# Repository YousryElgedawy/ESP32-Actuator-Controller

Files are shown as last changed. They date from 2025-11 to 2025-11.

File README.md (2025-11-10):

# ESP32-Actuator-Controller
24V / 20-Channel Actuator Control Board is equipped with an ESP32-S3 and a W5500 Ethernet module for network connectivity, featuring 20 MOSFET-based SSRs to manage actuators along with protection against reverse polarity, overvoltage, short circuits, and ESD.
Board Design Details

- Structure: 4-layer board with a Sig/GND/PWR/Sig stackup, utilizing outer layers for signal traces and inner layers for power distribution.  
- Power Layers: Constructed with 2-ounce copper to handle load currents and withstand high ambient temperatures.  
- Ground Planes:
Layer 2 serves as the main solid GND plane to ensure overall stability. 
Layer 4 features a GND polygon copper pour, functioning as a heat sink and forming a solid ground plane under Layer 3 to create capacitance with the PWR plane. 
A small GND plane is added on Layer 3 over Ethernet and SPI tracks to maintain the same reference plane and minimize impedance mismatch during top-layer routing changes.  
- Power Distribution: Layer 3 incorporates multi-rail polygons for 24V, 5V, and 3.3V supplies.   
Input power polygons are duplicated across layers and connected with stitching vias to support high current demands and minimize temperature rise.  
- High-Speed Signals: Ethernet and SPI signals are routed on the top layer with minimal layer changes, kept as short as possible, and isolated from noise sources including the buck converter, input power connector, and ESP32 antenna, with maximum distance maintained from these sources.   
- RJ45 Connector: Equipped with an internal transformer, Bob-Smith termination, and common-mode choke for optimal signal integrity.   
- SPI Lines: Designed with extremely short traces, maintained at 50-ohm impedance, and implemented with series termination to preserve signal integrity.   
- Power Supply: A cascaded LDO paired with a buck converter delivers a low-ripple power supply to the ESP32.  
- Signal Management: Signal buffers are employed to limit current sourced or sunk by the MCU.  
- Manufacturing Considerations:  
  Copper Balance: Meticulously maintained when connecting small components such as 0402 passives to prevent soldering defects such as tombstoning.   
  Thermal Relief Polygon Connection: Utilized for high-power through-hole components to enhance solderability.  
- Draftsman PDF: Contains all assembly notes and fabrication notes, specifying complete documentation for manufacturing and assembly processes.

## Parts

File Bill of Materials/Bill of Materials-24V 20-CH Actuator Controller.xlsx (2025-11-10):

LibRef | Manufacturer | Mfr. Part # | Supplier | Supplier Part # | Package | Price | Quantity | Multiplier | Extended Price
CAP 22uF 25V | Samsung Electro-Mechanics | CL21A226MAYNNNE | DigiKey | 1276-CL21A226MAYNNNECT-ND | 0805 | 0.43 | 4 | 1 | 1.72
CAP 100nF 50V | KEMET | C0603C104K5RACTU | DigiKey | 399-C0603C104K5RACTUCT-ND | 0603 | 0.11 | 20 | 1 | 2.2
CAP 4.7uF 50V | Murata Electronics | GRM21BZ71H475ME15K | DigiKey | 490-GRM21BZ71H475ME15KCT-ND | 0805 | 0.27 | 6 | 1 | 1.62
Electrolytic CAP 330uF 50V | Nichicon | UCM1H331MNL1GS | DigiKey | 493-14535-1-ND | SMD,D10.3xL10.3mm | 1.18 | 2 | 1 | 2.36
CAP 6.8nF 100V | Samsung Electro-Mechanics | CL05B682KC5VPNC | DigiKey | 1276-CL05B682KC5VPNCCT-ND | 0402 | 0.49 | 2 | 1 | 0.98
CAP 10nF 50V | KEMET | C0402C103K5REC7411 | DigiKey | 399-C0402C103K5REC7411CT-ND | 0402 | 0.56 | 2 | 1 | 1.12
CAP 1nF 2kV | Johanson Dielectrics | 202R18W102KV4E | DigiKey | 709-VPDD202W102K1GV001ECT-ND | 1206 | 0.17 | 1 | 1 | 0.17
CAP 22nF 50V | YAGEO | CC0402KRX7R9BB223 | DigiKey | 311-1722-1-ND | 0402 | 0.29 | 1 | 1 | 0.29
SMAZ15-13-F 15V Zener Diode | Diodes Incorporated | SMAZ15-13-F | DigiKey | SMAZ15-FDICT-ND | DO-214AC(SMA) | 0.28 | 1 | 1 | 0.28
SMAJ30A TVS Diode 30VRWM | Würth Elektronik | SMAJ30A | DigiKey | 732-SMAJ30ACT-ND | DO-214AC(SMA) | 0.29 | 1 | 1 | 0.29
SK510A-LTP 100V 5A Schottky Diode | MCC (Micro Commercial Components) | SK510A-LTP | DigiKey | SK510A-LTPMSCT-ND | DO-214AC(SMA) | 0.5 | 21 | 1 | 10.5
LED EMERALD | XINGLIGHT | XL-2012UGC | DigiKey | 5962-XL-2012UGCTR-ND | 0805 | 33.75 | 20 | 1 | 0.06
0456050.DRSDE Fuse 50A | Littelfuse Inc. | 0456050.DRSDE | DigiKey | 18-0456050.DRSDECT-ND | SMD,12.2 x 4.5 x 4.5 mm | 6.13 | 1 | 1 | 6.13
BLM15PX121SN1D Ferrite Bead 120Ω | Murata Electronics | BLM15PX121SN1D | DigiKey | 490-9656-1-ND | 0402 | 0.1 | 1 | 1 | 0.1
Terminal Block 2P 57A | Würth Elektronik | 691256610002 | DigiKey | 732-11031-ND | Through Hole, P=10.16mm | 3.36 | 1 | 1 | 3.36
USB2.0 Type-C Connector | Amphenol ICC (Commercial Products) | 12402012E212A | DigiKey | 664-12402012E212ACT-ND | SMD | 0.61 | 1 | 1 | 0.61
7499011121A RJ45 Connector | Würth Elektronik | 7499011121A | DigiKey | 732-4509-5-ND | Through Hole | 6.55 | 1 | 1 | 6.55
Terminal Block 10P 14A | Würth Elektronik | 691242510010 | DigiKey | 732-691242510010-ND | Through Hole, P=5.08mm | 5.17 | 4 | 1 | 20.68
IC Socket 6P | TE Connectivity AMP Connectors | 1-2199298-1 | DigiKey | A120346-ND | DIP-6 | 0.21 | 20 | 1 | 4.2
G3VM-61BR2 60V 4/8 A SSR | Omron Electronics Inc-EMC Div | G3VM-61BR2 | DigiKey | 39-G3VM-61BR2-ND | DIP-6 | 10.71 | 20 | 1 | 214.2
10uH 7A Inductor | Pulse Electronics | PM5432.103NLT | DigiKey | 553-PM5432.103NLTCT-ND | SMD, 6.8x6.6 | 1.83 | 1 | 1 | 1.83
MOSFET P-CH 40V 100A | Toshiba Semiconductor and Storage | XPH3R114MC,L1XHQ | DigiKey | 264-XPH3R114MCL1XHQCT-ND | 8-SOP Advance (5x5) | 1.82 | 2 | 1 | 3.64
RES 162k | YAGEO | RC0603FR-07162KL | DigiKey | 311-162KHRCT-ND | 0603 | 0.06 | 3 | 1 | 0.06
RES 2.4M | YAGEO | RC0603FR-072M4L | DigiKey | 13-RC0603FR-072M4LCT-ND | 0603 | 0.11 | 1 | 1 | 0.11
RES 22.1k | YAGEO | RT0603FRE0722K1L | DigiKey | 13-RT0603FRE0722K1LCT-ND | 0603 | 0.14 | 1 | 1 | 0.14
RES 5.1k | YAGEO | RC0603FR-075K1L | DigiKey | 311-5.10KHRCT-ND | 0603 | 0.07 | 2 | 1 | 0.07
RES 22R | YAGEO | RC0402FR-0722RL | DigiKey | 311-22.0LRCT-ND | 0402 | 0.07 | 9 | 1 | 0.07
RES 12.4k | YAGEO | RC0603FR-0712K4L | DigiKey | 311-12.4KHRCT-ND | 0603 | 0.07 | 23 | 1 | 0.07
RES 49.9R | YAGEO | RC0402FR-0749R9L | DigiKey | 311-49.9LRCT-ND | 0402 | 0.2 | 4 | 1 | 0.2
RES 4.7k | YAGEO | RC0603FR-074K7L | DigiKey | 311-4.70KHRCT-ND | 0603 | 0.09 | 6 | 1 | 0.09
RES 470R | YAGEO | RT0603FRE07470RL | DigiKey | YAG5742CT-ND | 0603 | 0.1 | 22 | 1 | 0.1
RES 10R | YAGEO | AC0402FR-0710RL | DigiKey | YAG3438CT-ND | 0402 | 0.1 | 2 | 1 | 0.1
Tactile Switch | ALPSALPINE | SKRPANE010 | DigiKey | 4809-SKRPANE010CT-ND | SMD | 0.27 | 2 | 1 | 0.54
LDO 3V3 2A | STMicroelectronics | LD39200PU33R | DigiKey | 497-15229-1-ND | DFN-6(3x3) | 1.05 | 1 | 1 | 1.05
LMR51430YDDCR Buck Converter | Texas Instruments | LMR51430YDDCR | DigiKey | 296-LMR51430YDDCRCT-ND | TSOT-23-6 | 1.58 | 1 | 1 | 1.58
ESP32-S3-MINI-1-N8 | Espressif Systems | ESP32-S3-MINI-1-N8 | DigiKey | 5407-ESP32-S3-MINI-1-N8CT-ND | SMD | 5.28 | 1 | 1 | 5.28
USBLC6-2SC6 ESD Array 5.25VRWM | STMicroelectronics | USBLC6-2SC6 | DigiKey | 497-5235-1-ND | SOT-23-6L | 0.36 | 3 | 1 | 1.08
W5500 SPI to Ethernet | WIZnet | W5500 | DigiKey | 1278-W5500CT-ND | LQFP-48(7x7) | 3.67 | 1 | 1 | 3.67
SN74LV4T125PWR Non-Inverting Buffer | Texas Instruments | SN74LV4T125PWR | DigiKey | 296-40545-1-ND | 14-TSSOP | 0.79 | 5 | 1 | 3.95
25MHz HCMOS Oscillator | ECS Inc. | ECS-2520MV-250-BN-TR | DigiKey | XC2751CT-ND | 4-SMD (2.5x2) | 1.16 | 1 | 1 | 1.16
 |  |  |  |  |  |  |  | Total Price | 302.21

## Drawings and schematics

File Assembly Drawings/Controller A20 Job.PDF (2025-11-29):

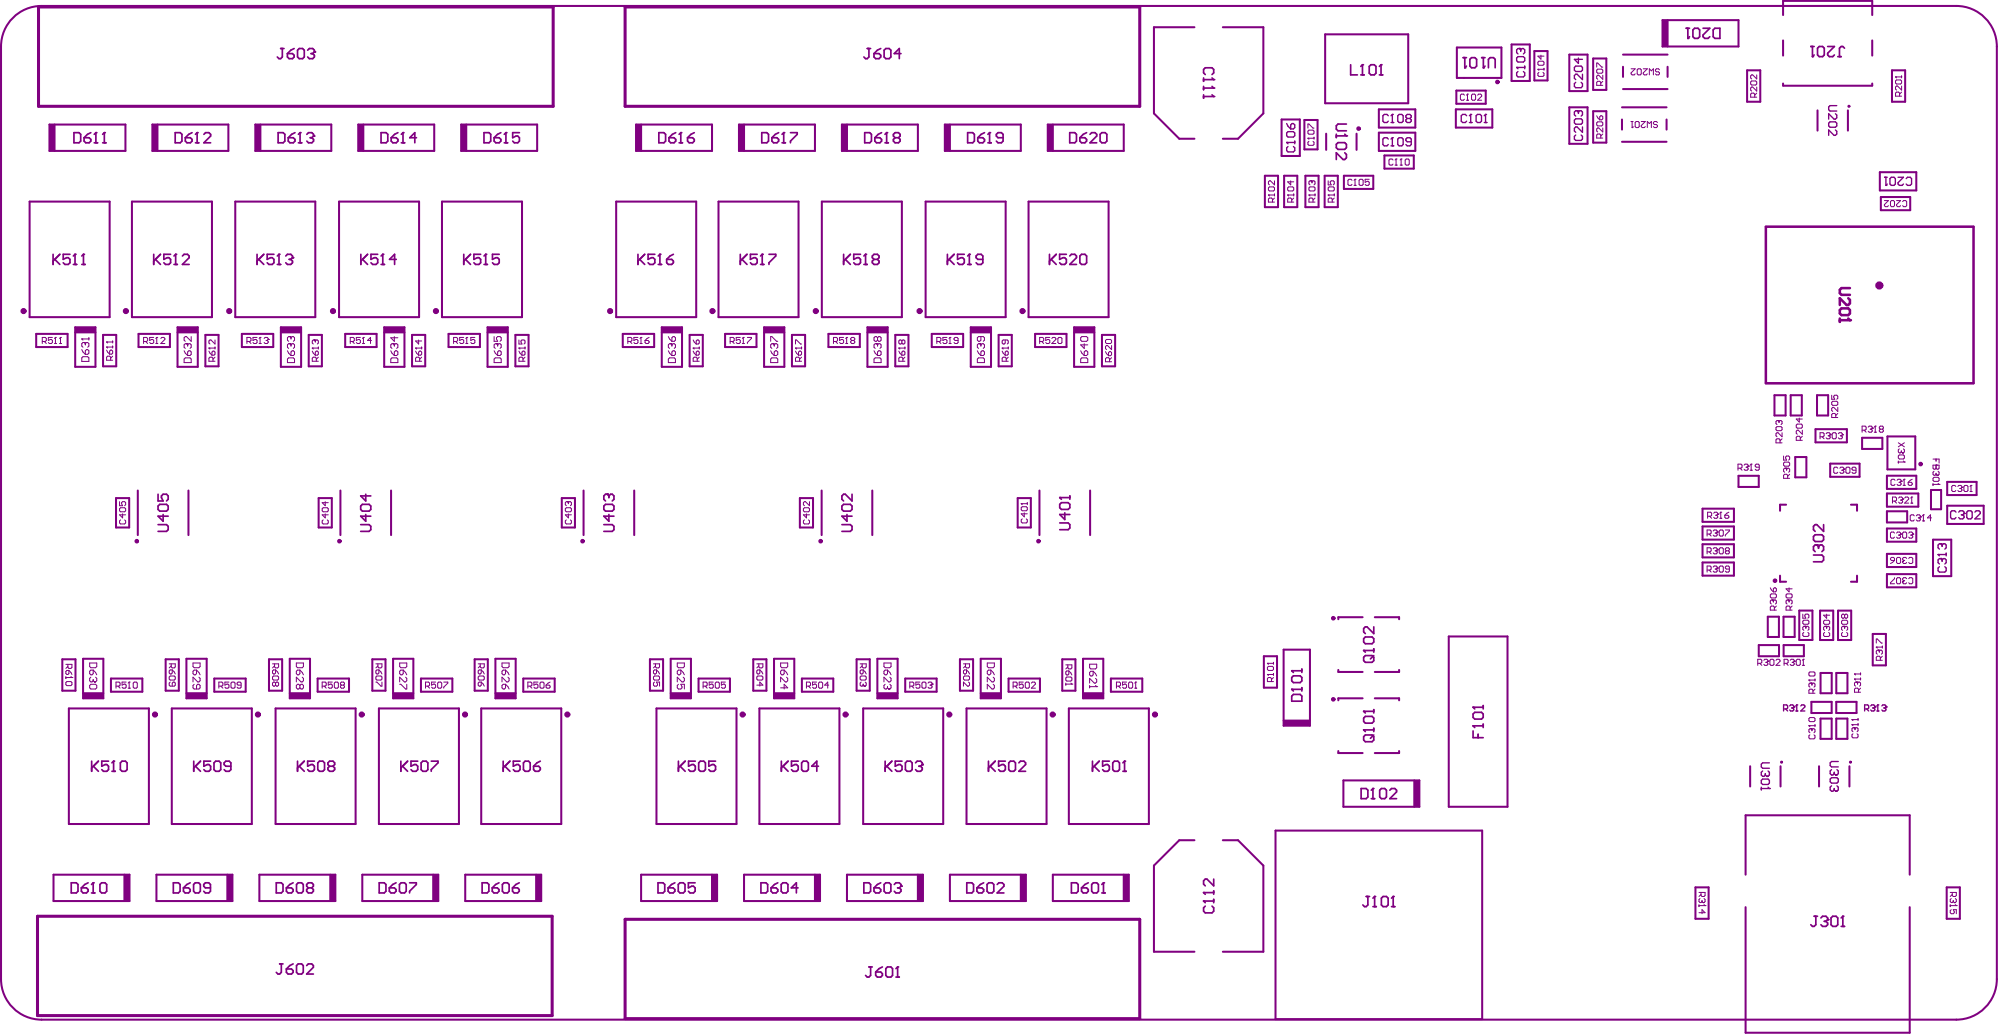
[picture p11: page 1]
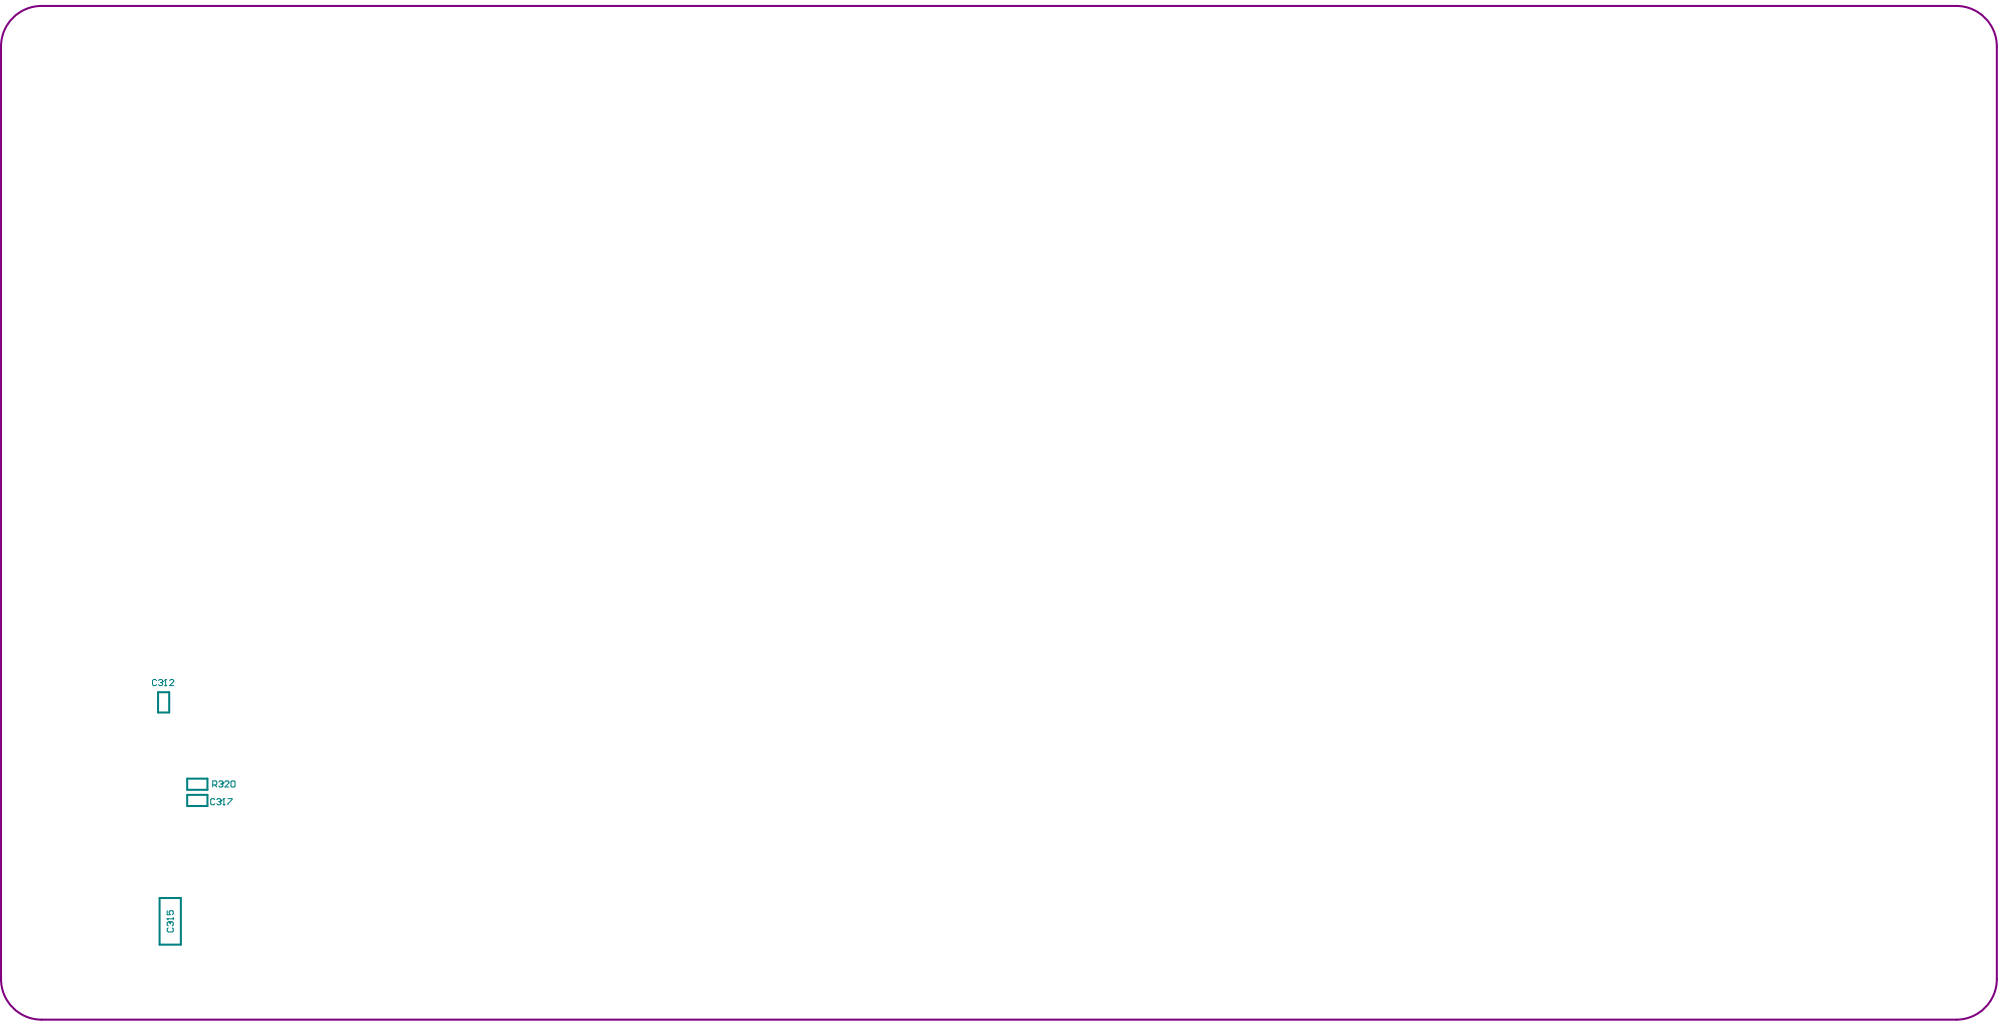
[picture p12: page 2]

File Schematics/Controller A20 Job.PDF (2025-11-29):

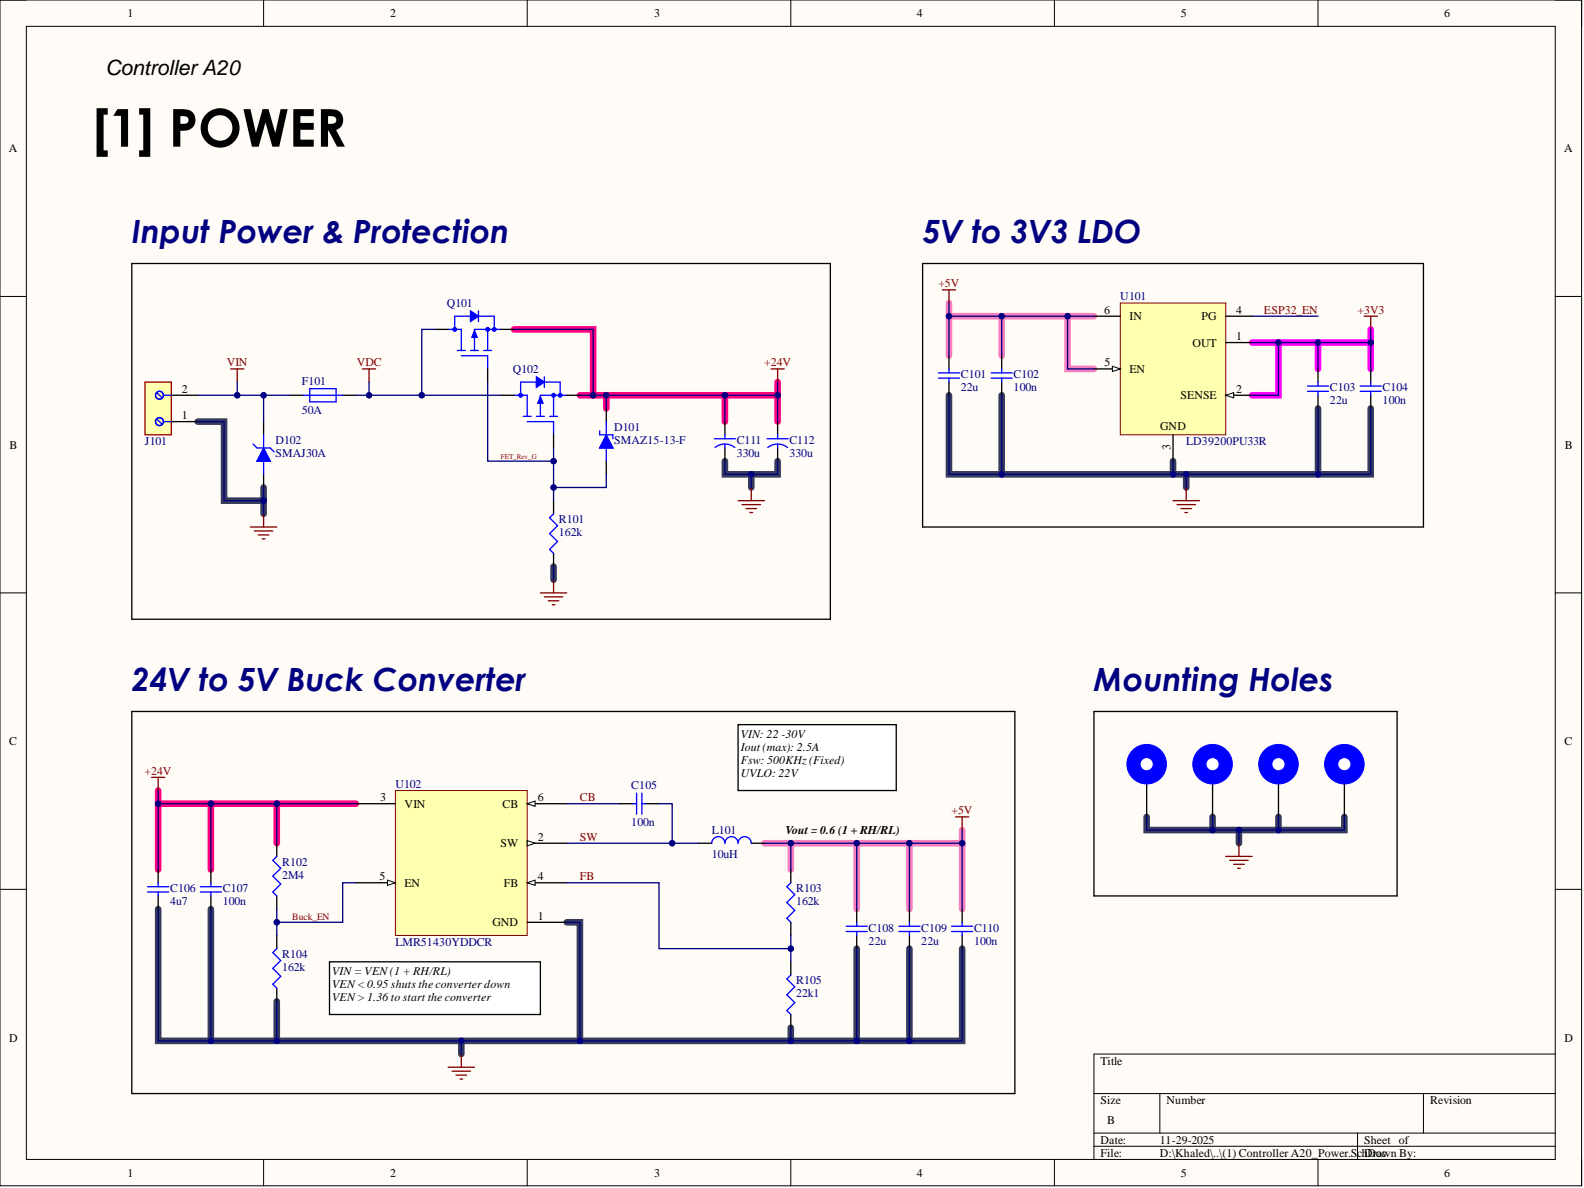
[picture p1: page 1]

Buck_EN

VIN = VEN (1 + RH/RL)
VEN < 0.95 shuts the converter down
VEN > 1.36 to start the converter

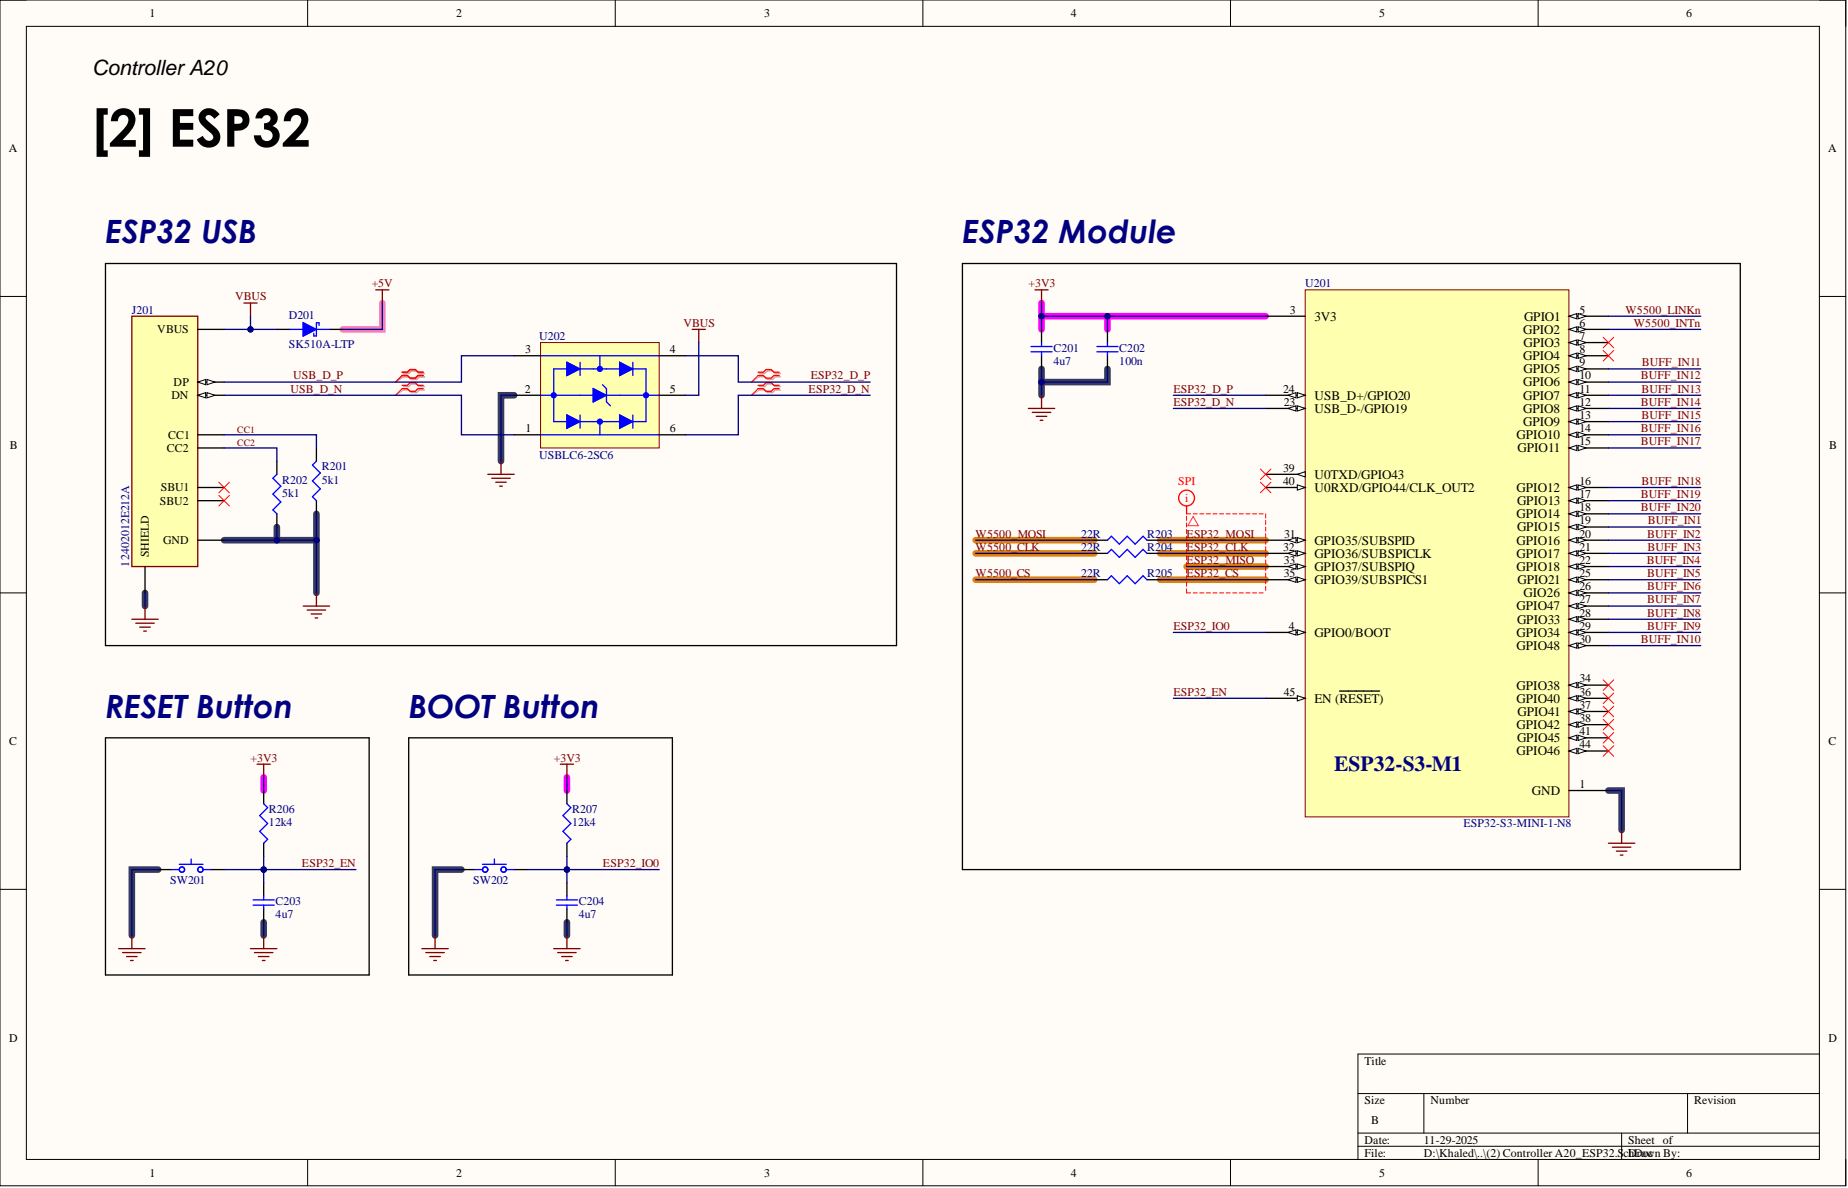
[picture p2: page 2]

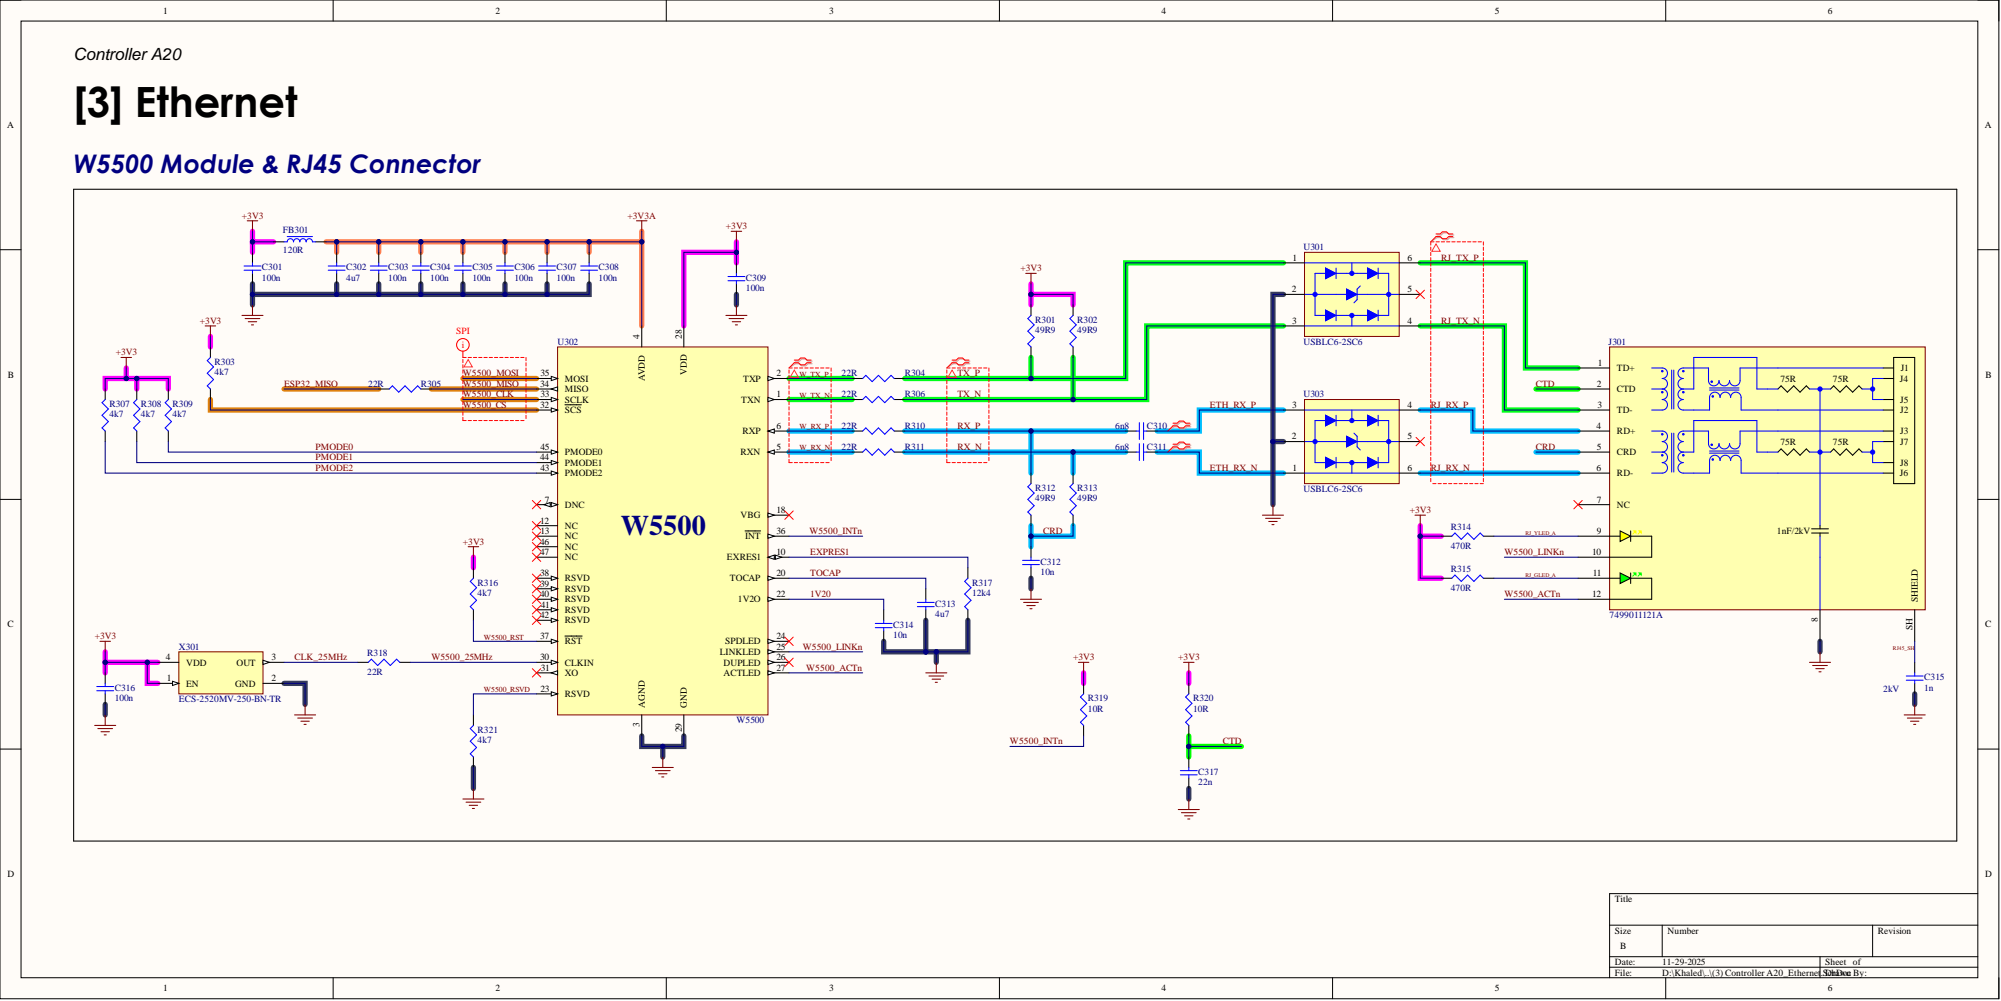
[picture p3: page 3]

W 5 5 0 0 _ M I S O | 3
W 5 5 0 0 _ C LK | 3

RJ _RX _N | CRD 5 6

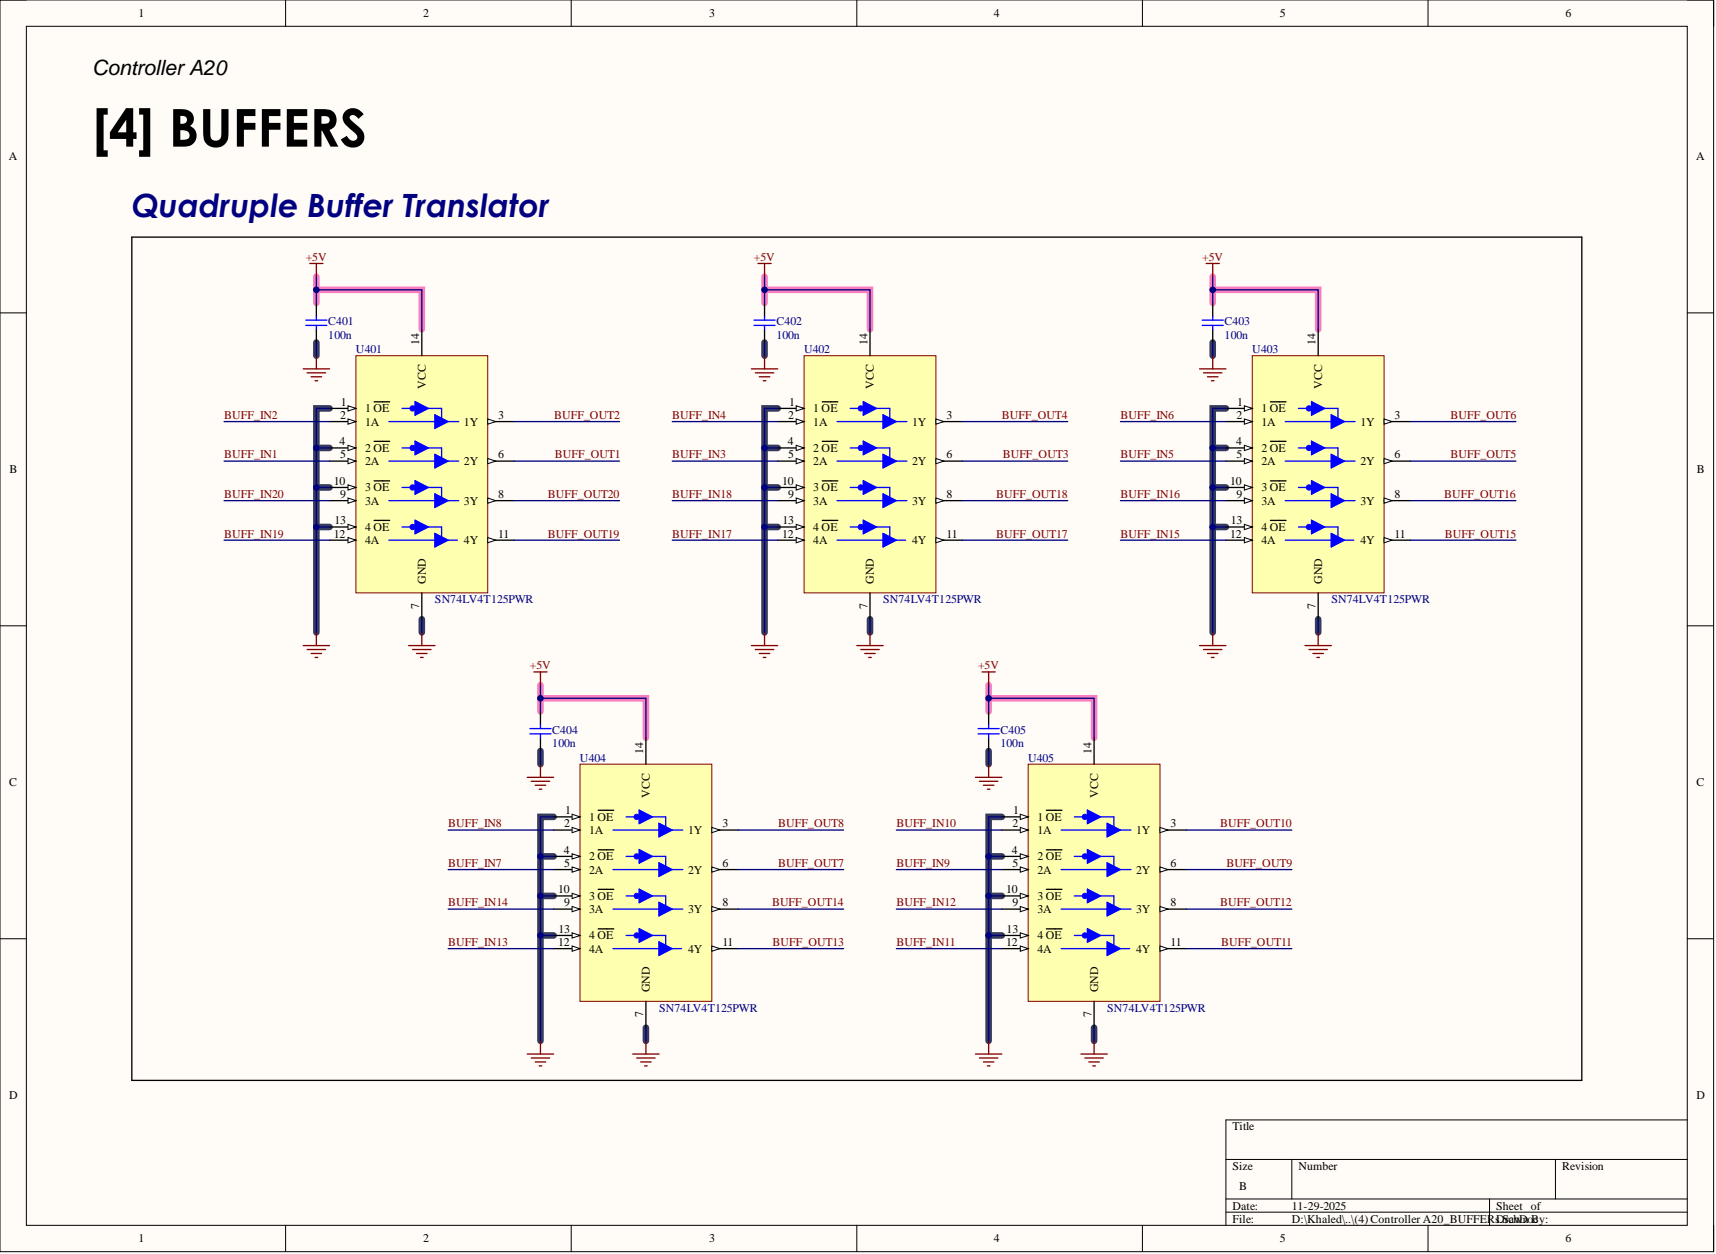
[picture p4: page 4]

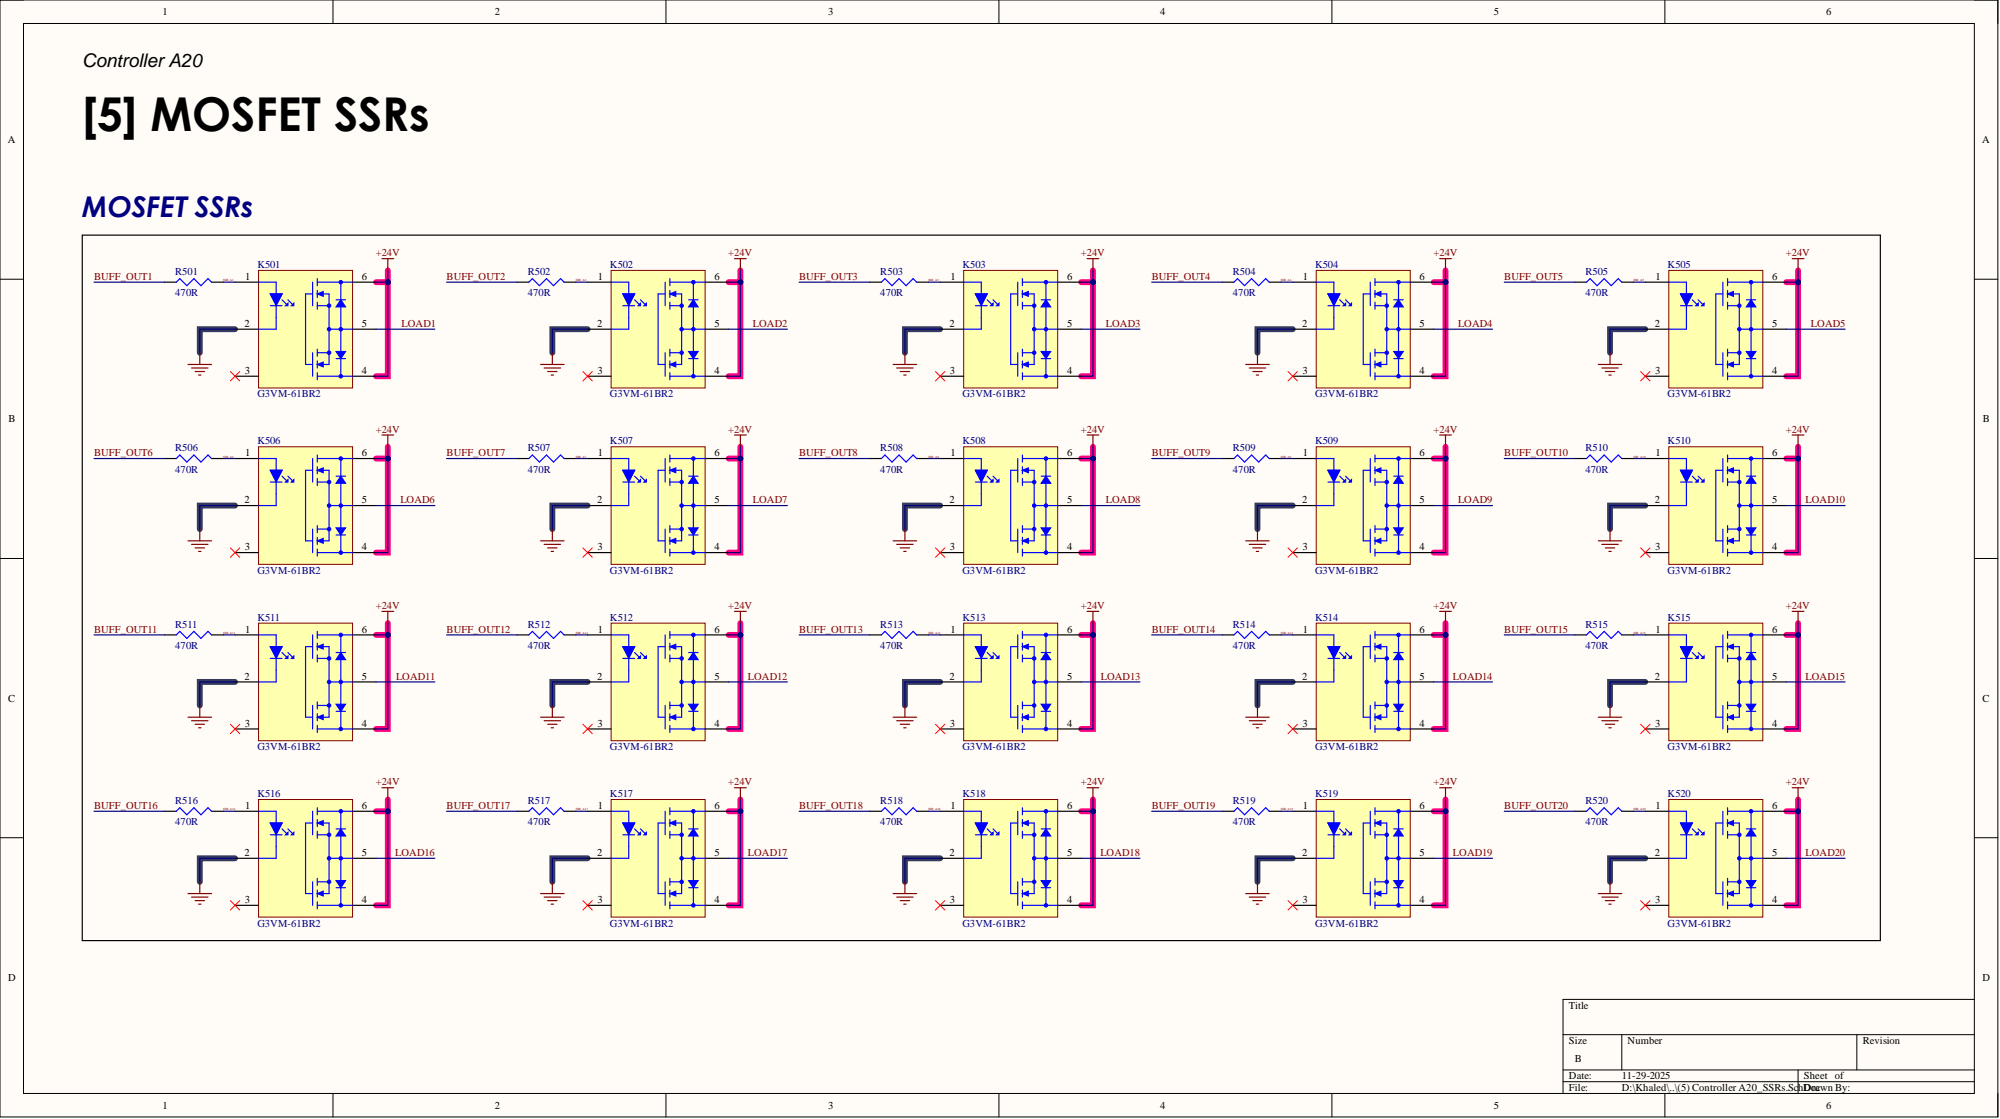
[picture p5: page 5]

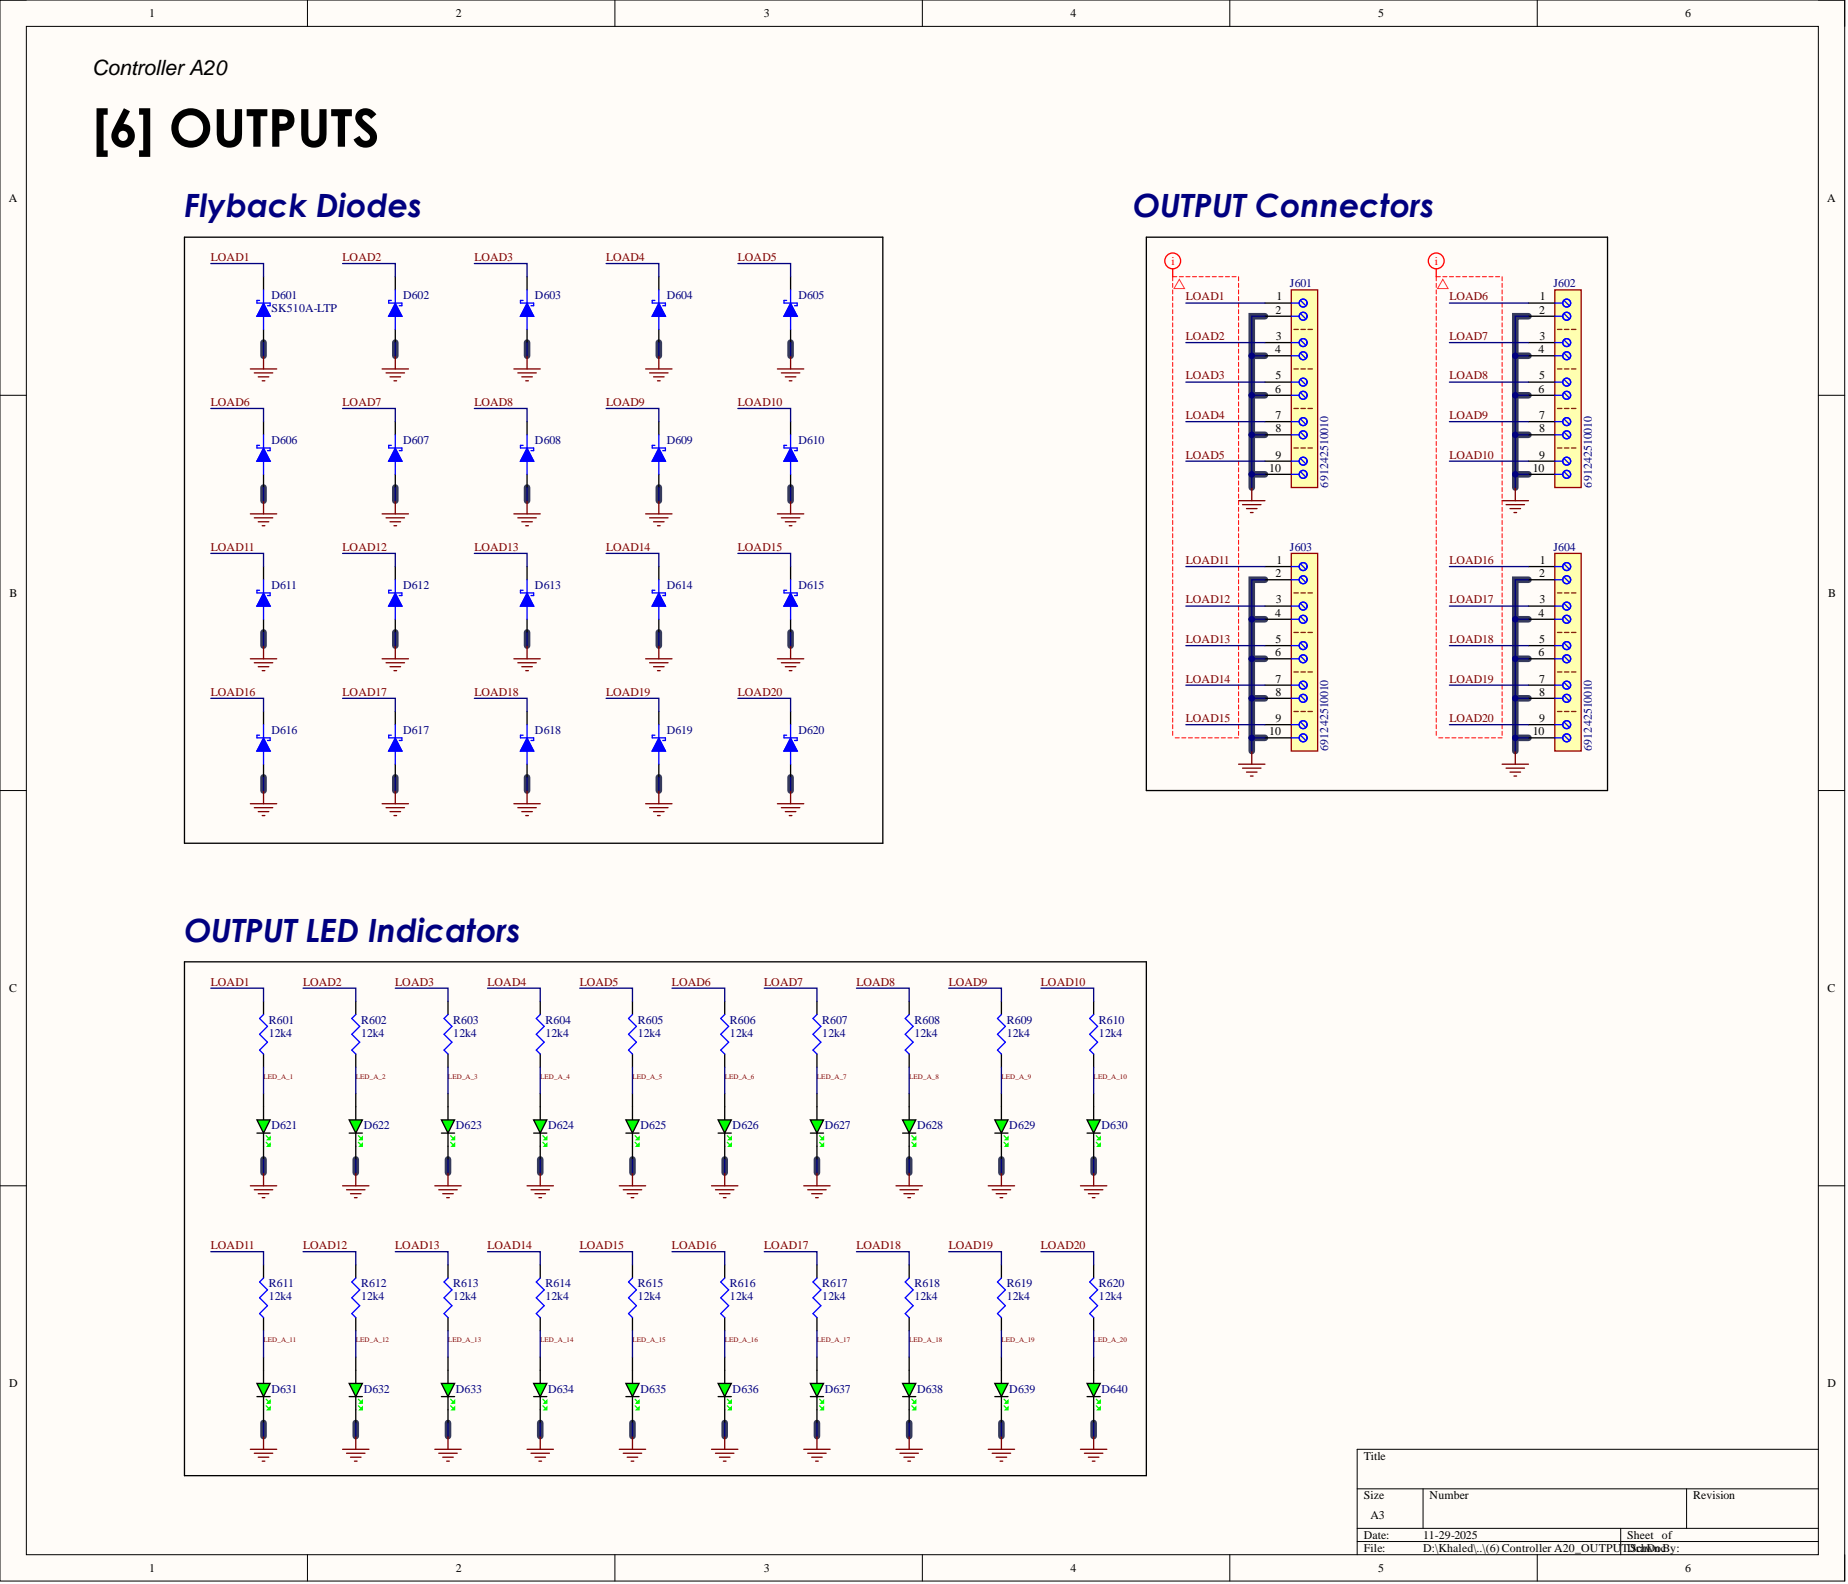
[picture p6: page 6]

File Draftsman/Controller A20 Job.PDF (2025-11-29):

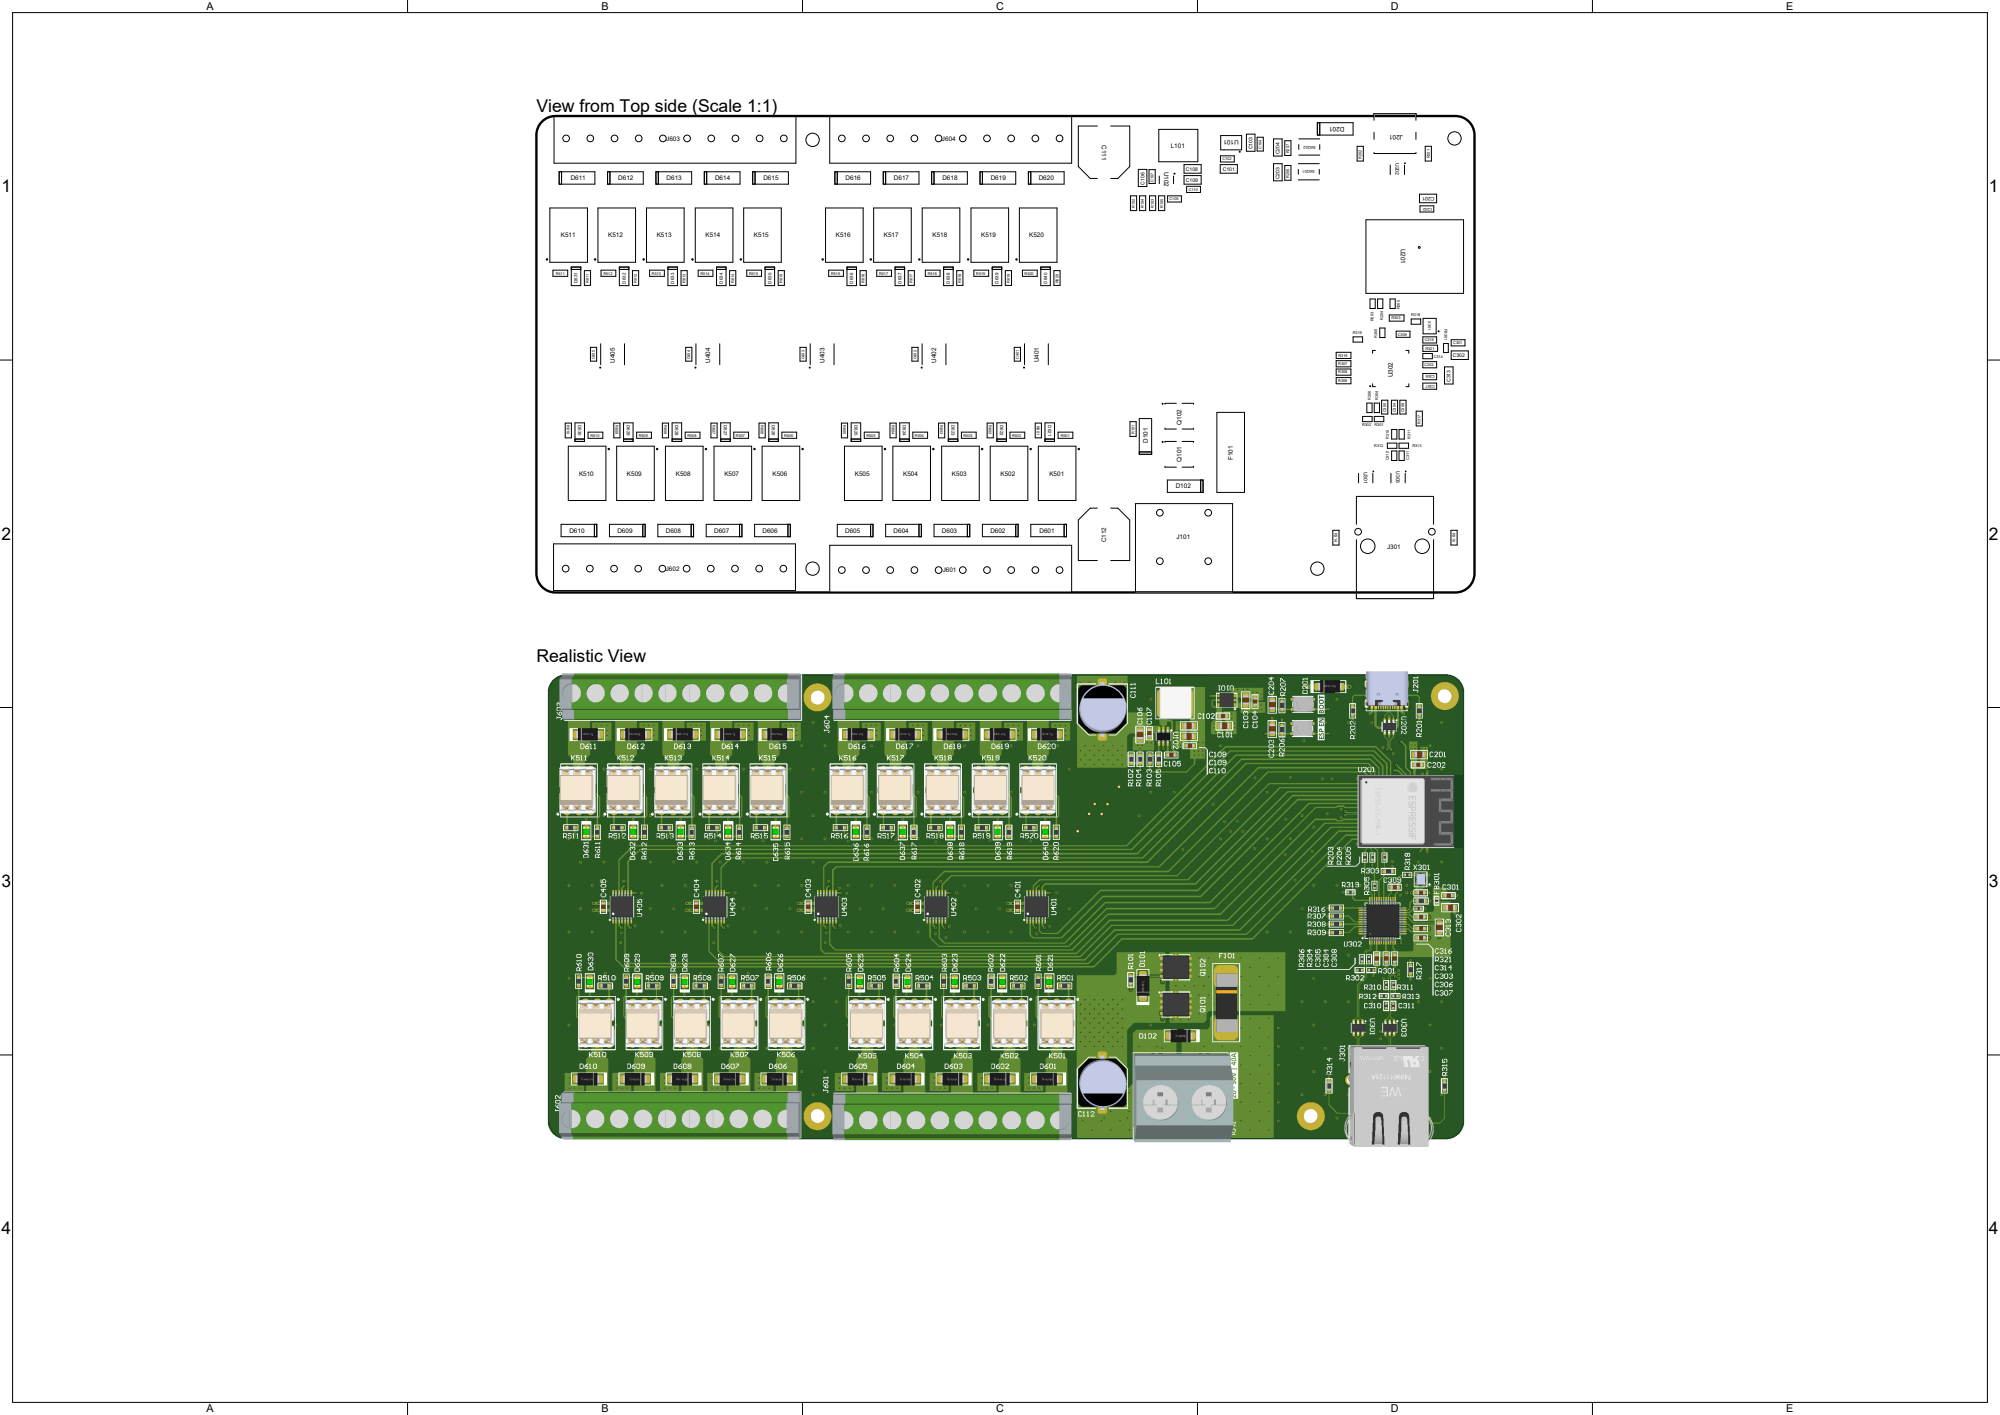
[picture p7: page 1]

View from Top side (Scale 1:1)

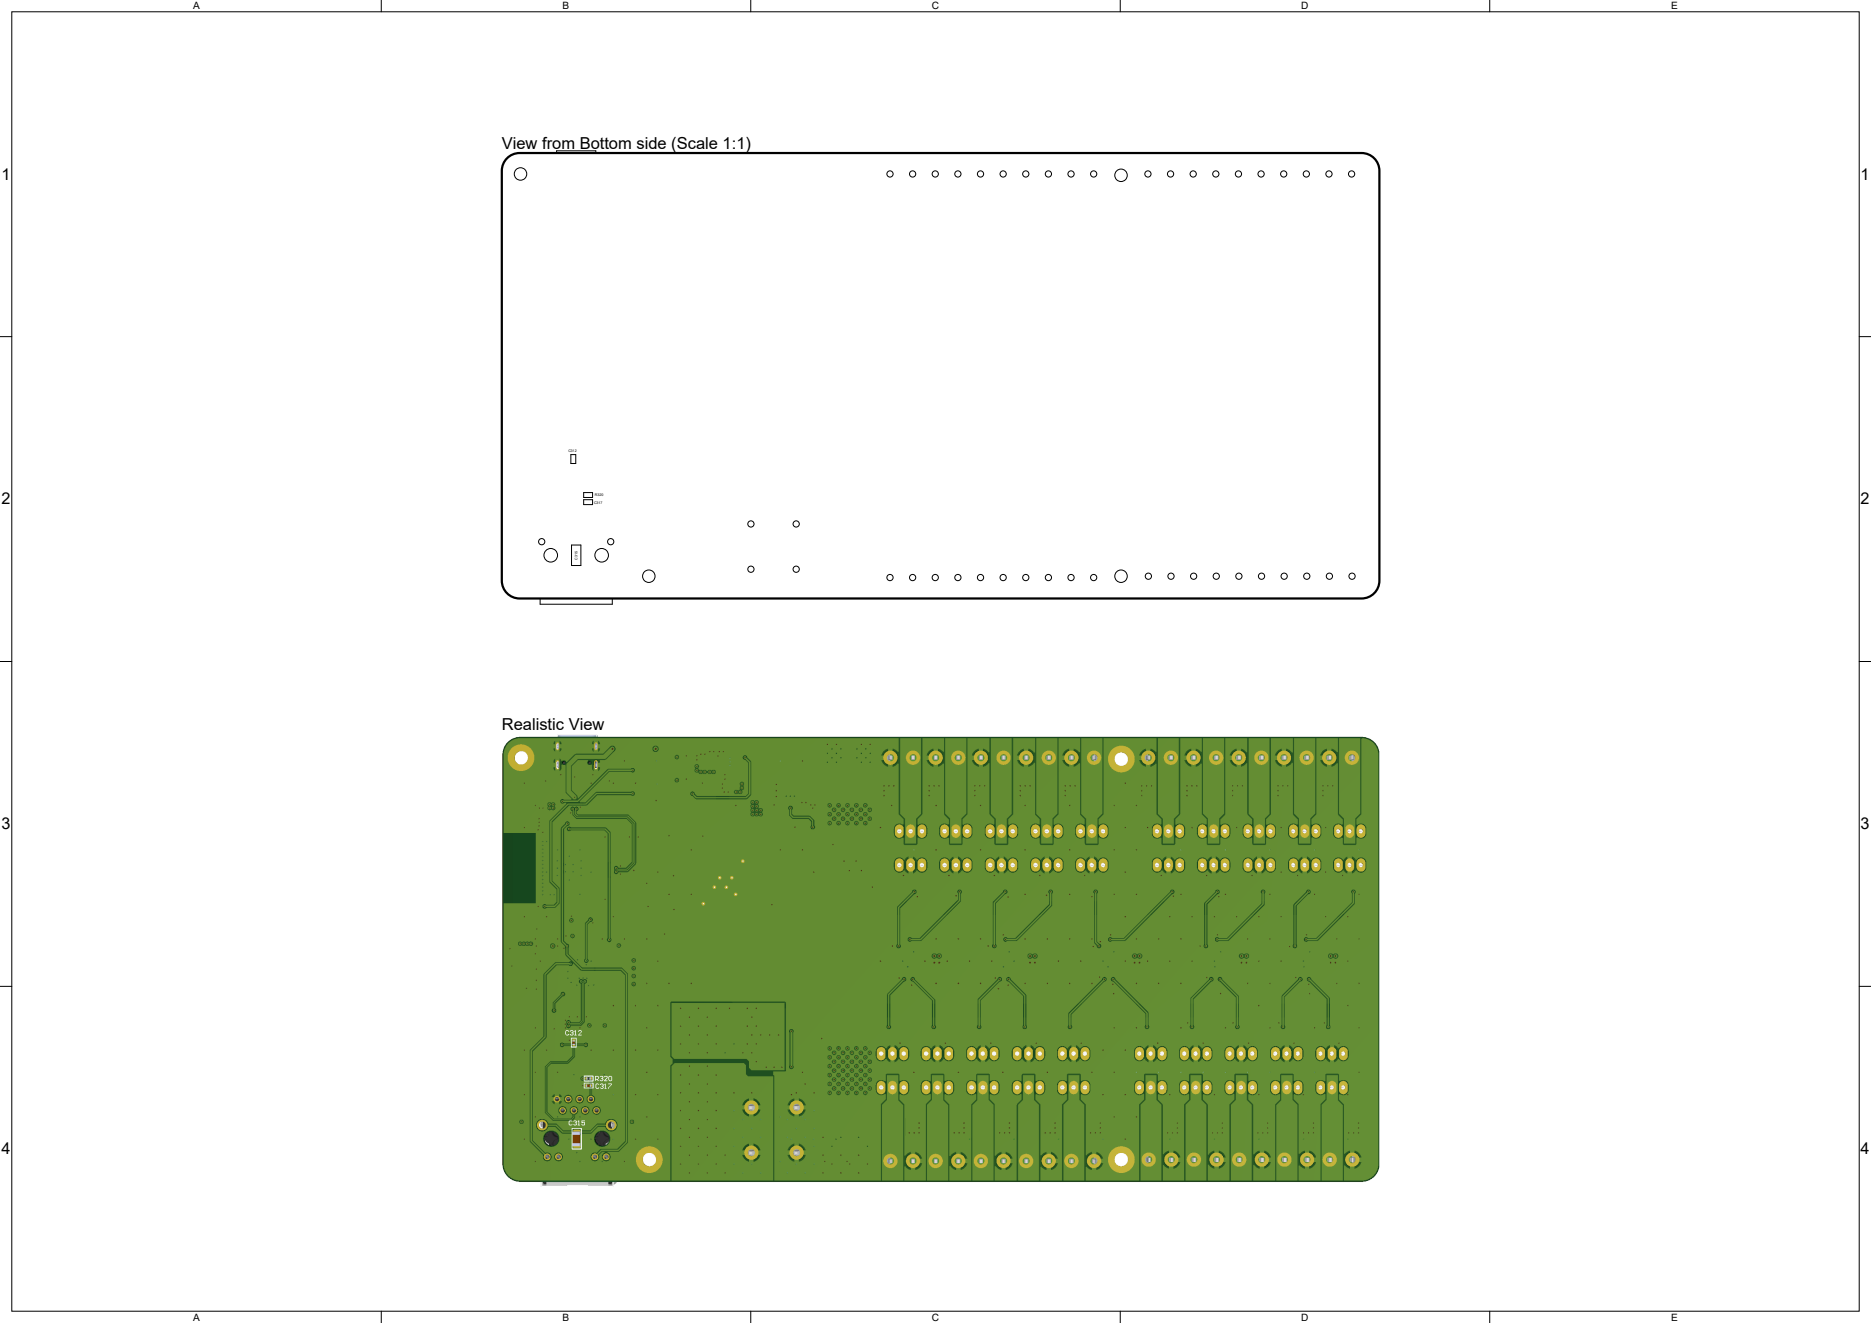
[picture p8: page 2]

View from Bottom side (Scale 1:1)

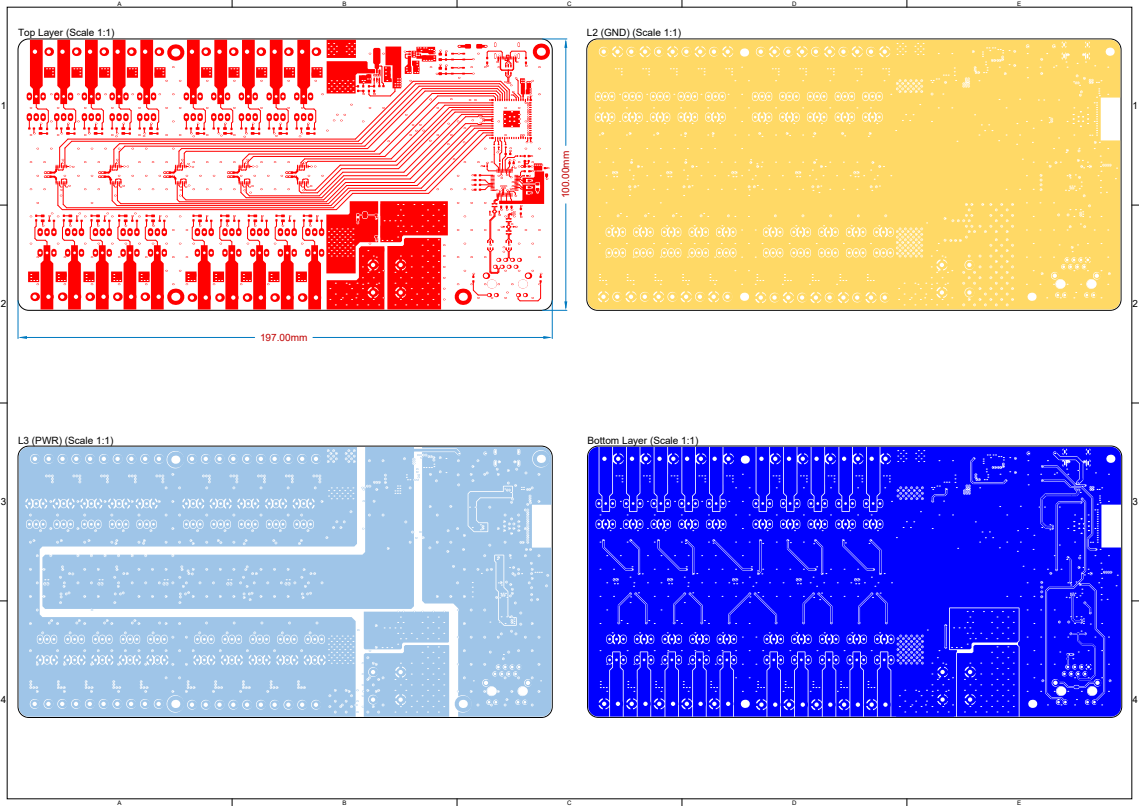
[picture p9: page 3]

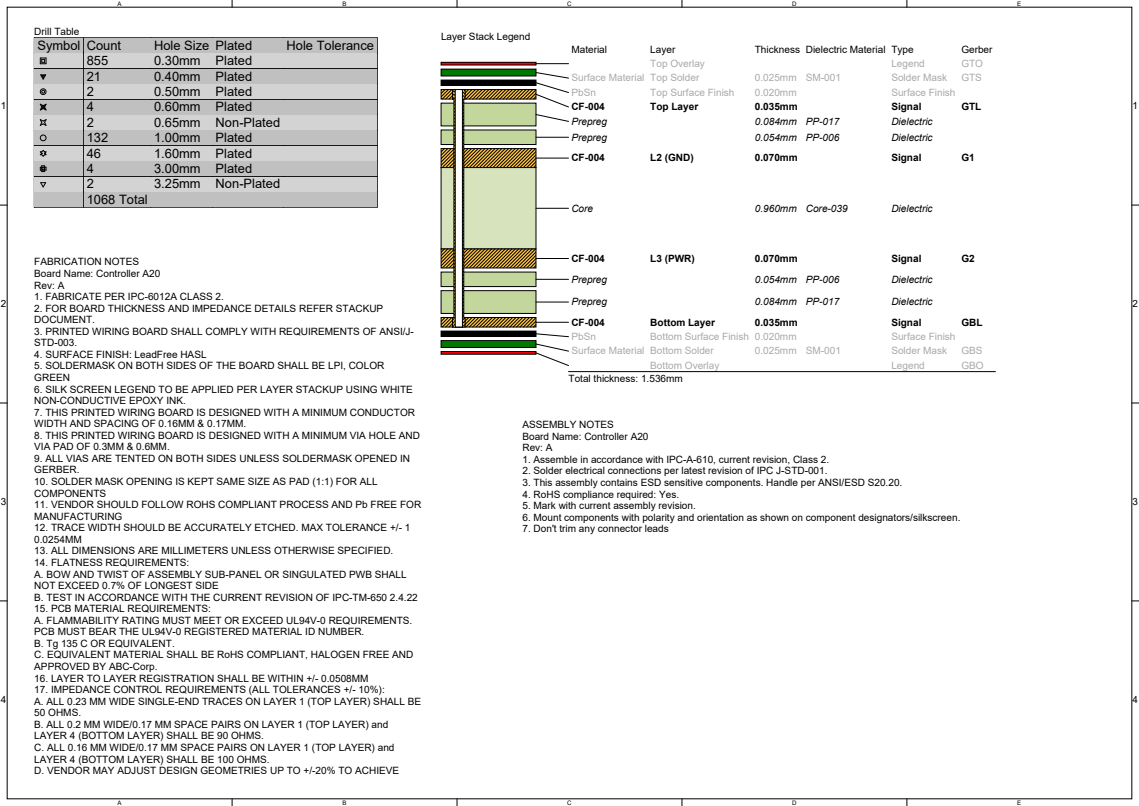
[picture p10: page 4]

Symbol | Count | Hole Size | Plated | Hole Tolerance

855 | 0.30mm | Plated
21 | 0.40mm | Plated
2 | 0.50mm | Plated
4 | 0.60mm | Plated
2 | 0.65mm | Non-Plated
132 | 1.00mm | Plated
46 | 1.60mm | Plated
4 | 3.00mm | Plated
2 | 3.25mm | Non-Plated
1068 Total

FABRICATION NOTES
Board Name: Controller A20
Rev: A
1. FABRICATE PER IPC-6012A CLASS 2.
2. FOR BOARD THICKNESS AND IMPEDANCE DETAILS REFER STACKUP
DOCUMENT.
3. PRINTED WIRING BOARD SHALL COMPLY WITH REQUIREMENTS OF ANSI/J-
STD-003.
4. SURFACE FINISH: LeadFree HASL
5. SOLDERMASK ON BOTH SIDES OF THE BOARD SHALL BE LPI, COLOR
GREEN
6. SILK SCREEN LEGEND TO BE APPLIED PER LAYER STACKUP USING WHITE
NON-CONDUCTIVE EPOXY INK.
7. THIS PRINTED WIRING BOARD IS DESIGNED WITH A MINIMUM CONDUCTOR
WIDTH AND SPACING OF 0.16MM & 0.17MM.
8. THIS PRINTED WIRING BOARD IS DESIGNED WITH A MINIMUM VIA HOLE AND
VIA PAD OF 0.3MM & 0.6MM.
9. ALL VIAS ARE TENTED ON BOTH SIDES UNLESS SOLDERMASK OPENED IN
GERBER.
10. SOLDER MASK OPENING IS KEPT SAME SIZE AS PAD (1:1) FOR ALL
COMPONENTS
11. VENDOR SHOULD FOLLOW ROHS COMPLIANT PROCESS AND Pb FREE FOR
MANUFACTURING
12. TRACE WIDTH SHOULD BE ACCURATELY ETCHED. MAX TOLERANCE +/- 1
13. ALL DIMENSIONS ARE MILLIMETERS UNLESS OTHERWISE SPECIFIED.
14. FLATNESS REQUIREMENTS:
A. BOW AND TWIST OF ASSEMBLY SUB-PANEL OR SINGULATED PWB SHALL
NOT EXCEED 0.7% OF LONGEST SIDE
B. TEST IN ACCORDANCE WITH THE CURRENT REVISION OF IPC-TM-650 2.4.22
15. PCB MATERIAL REQUIREMENTS:
A. FLAMMABILITY RATING MUST MEET OR EXCEED UL94V-0 REQUIREMENTS.
PCB MUST BEAR THE UL94V-0 REGISTERED MATERIAL ID NUMBER.
B. Tg 135 C OR EQUIVALENT.
C. EQUIVALENT MATERIAL SHALL BE RoHS COMPLIANT, HALOGEN FREE AND
APPROVED BY ABC-Corp.
16. LAYER TO LAYER REGISTRATION SHALL BE WITHIN +/- 0.0508MM
17. IMPEDANCE CONTROL REQUIREMENTS (ALL TOLERANCES +/- 10%):
A. ALL 0.23 MM WIDE SINGLE-END TRACES ON LAYER 1 (TOP LAYER) SHALL BE
50 OHMS.
B. ALL 0.2 MM WIDE/0.17 MM SPACE PAIRS ON LAYER 1 (TOP LAYER) and
LAYER 4 (BOTTOM LAYER) SHALL BE 90 OHMS.
C. ALL 0.16 MM WIDE/0.17 MM SPACE PAIRS ON LAYER 1 (TOP LAYER) and
LAYER 4 (BOTTOM LAYER) SHALL BE 100 OHMS.
D. VENDOR MAY ADJUST DESIGN GEOMETRIES UP TO +/-20% TO ACHIEVE

ASSEMBLY NOTES
1. Assemble in accordance with IPC-A-610, current revision, Class 2.
2. Solder electrical connections per latest revision of IPC J-STD-001.
3. This assembly contains ESD sensitive components. Handle per ANSI/ESD S20.20.
4. RoHS compliance required: Yes.
5. Mark with current assembly revision.
6. Mount components with polarity and orientation as shown on component designators/silkscreen.
7. Don't trim any connector leads
